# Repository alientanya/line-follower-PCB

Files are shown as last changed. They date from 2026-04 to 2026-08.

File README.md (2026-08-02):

# FLF Bot Modular PCB

A modular PCB platform for Fast Line Follower (FLF) robots, designed to prioritize sensor experimentation and component flexibility.
This board allows multiple sensor array designs to be used interchangeably without redesigning the core electronics.
Instead of committing to a single sensor layout, this PCB supports four distinct sensor array designs, all compatible with the same base system.

---

## Menu

- [Hardware Revisions](#hardware-revisions)
- [Repository Structure](#repository-structure)
- [Core Features](#core-features)  
- [Core Components & Design Choices](#core-components--design-choices)  
- [Sensors](#sensors)  
- [Interchangeable Sensor Arrays](#interchangeable-sensor-arrays)  
- [8+1 Sensor Placement Strategy](#81-sensor-placement-strategy)  
- [Main Control PCB](#main-control-pcb)  
- [MCU Control](#mcu-control)  
- [Detailed Module Documentation](#detailed-module-documentation)
- [Design Considerations](#design-considerations)  
- [License](#license)

---

## Hardware Revisions

- **Lavender 1.0 (Blackpill version)** —   
  Fully designed, fabricated, assembled, and successfully deployed on the physical FLF robot. Uses the STM32F411 Blackpill module.
- **Lavender 2.0 (IC version)** —   
  Work-in-progress experimental design integrating a discrete STM32F411 IC directly onto the PCB.

---

## Repository Structure

```text
├── Lavender 1.0 (Blackpill vers)/    # Hardware-verified revision used on the physical robot
│   ├── line follower simple.kicad_pcb # Main body PCB layout
│   ├── line follower simple.kicad_sch # Main body schematic
│   ├── QRE1113.kicad_sch              # 16-Sensor QRE1113 schematic
│   ├── TCRT_sensors.kicad_sch         # 9-Sensor TCRT5000 schematic
│   ├── customssensor.kicad_sch        # Custom IR LED + PT334 schematic
│   ├── layerconnect.kicad_sch         # Inter-board connector schematic
│   └── FLF_gerbers/                   # Production Gerber output files
├── Lavender 2.0 (IC vers)/           # WIP prototype with discrete STM32 IC
│   ├── STMf411.kicad_sch              # Discrete STM32F411 MCU schematic
│   └── line follower simple.kicad_pcb # 2.0 PCB layout (WIP)
├── PCB customs/                       # 3D STEP models & custom KiCad footprint libraries
├── docs/                              # Detailed hardware documentation guides
│   ├── MODULES.md                     # Circuit modules & subsystem technical reference
│   ├── SENSOR_ARRAYS.md               # Sensor array designs & 8+1 strategy guide
│   └── PINOUTS_AND_REVISIONS.md       # Pin mapping & revision comparison guide
├── images/                            # PCB renders and schematic diagrams
├── LICENSE                            # MIT License
└── README.md                          # Main project README
```

---

## Core Features

* 4 interchangeable sensor array designs
* Modular architecture using headers
* STM32F411 (Blackpill) based control (Lavender 1.0)
* HC-05 Bluetooth connectivity
* Stackable PCB with internal battery space

---

## Core Components & Design Choices

### Microcontroller —  (Blackpill)

* High-speed ADC for sensor reading
* Rich GPIO availability
* Hardware timers for motor PWM
* Plug-in module → easy replacement

---

### Motor Driver — 

* Dual DC motor driver
* Efficient and compact
* Suitable for N20 motors

---

### Voltage Regulation — 

* Buck converter → stable 3.3V
* High efficiency for battery operation
* Adjustable output

---

### Communication — 

* UART-based Bluetooth module
* Used for debugging and tuning
* Supports STATE and EN pins

---

### Analog Multiplexer — 

* 16-channel analog MUX
* Used in high-density sensor configuration
* Reduces MCU pin usage

---

## Sensors

#### 

* Compact reflective IR sensor
* Fast response
* Used in high-density and simple arrays

#### 

* Larger footprint
* More tolerant of alignment and height

#### 

* Discrete design
* Custom Sensors
* Fully tunable sensitivity

---

## Interchangeable Sensor Arrays

All arrays share a common connector interface, making them plug-and-play.

### 1. 16-Sensor Curved Array (QRE1113 + MUX)
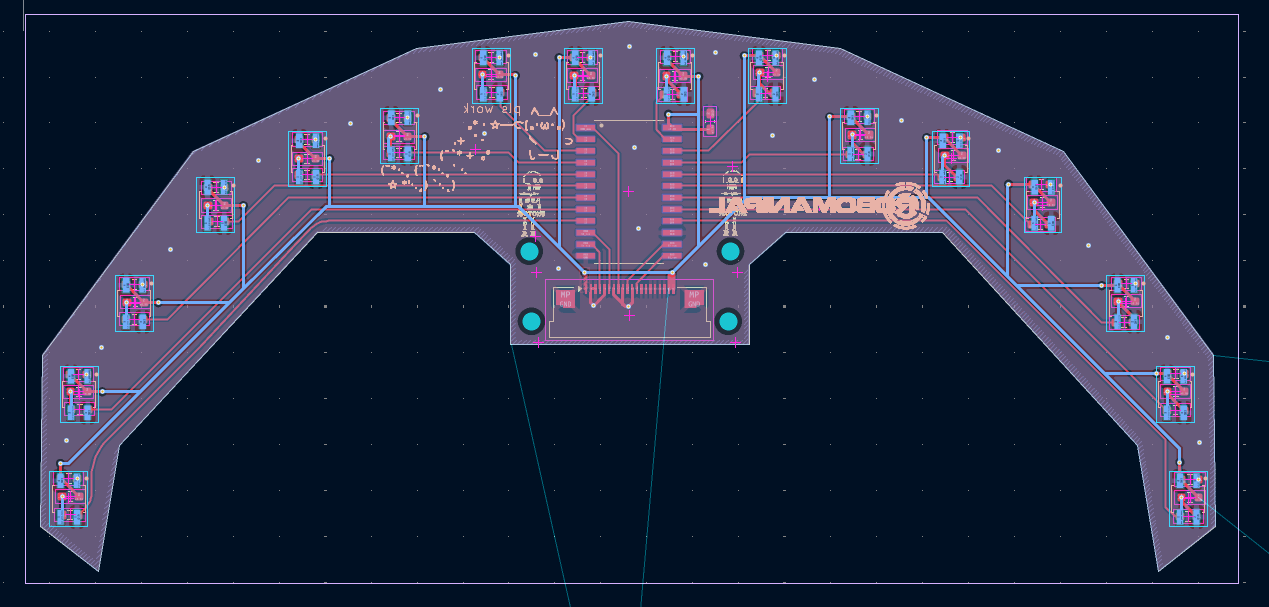
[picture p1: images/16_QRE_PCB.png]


* High resolution                            
* Uses 74HC4067
* Designed for aggressive curves

### 2. 9-Sensor Straight Array (QRE1113)
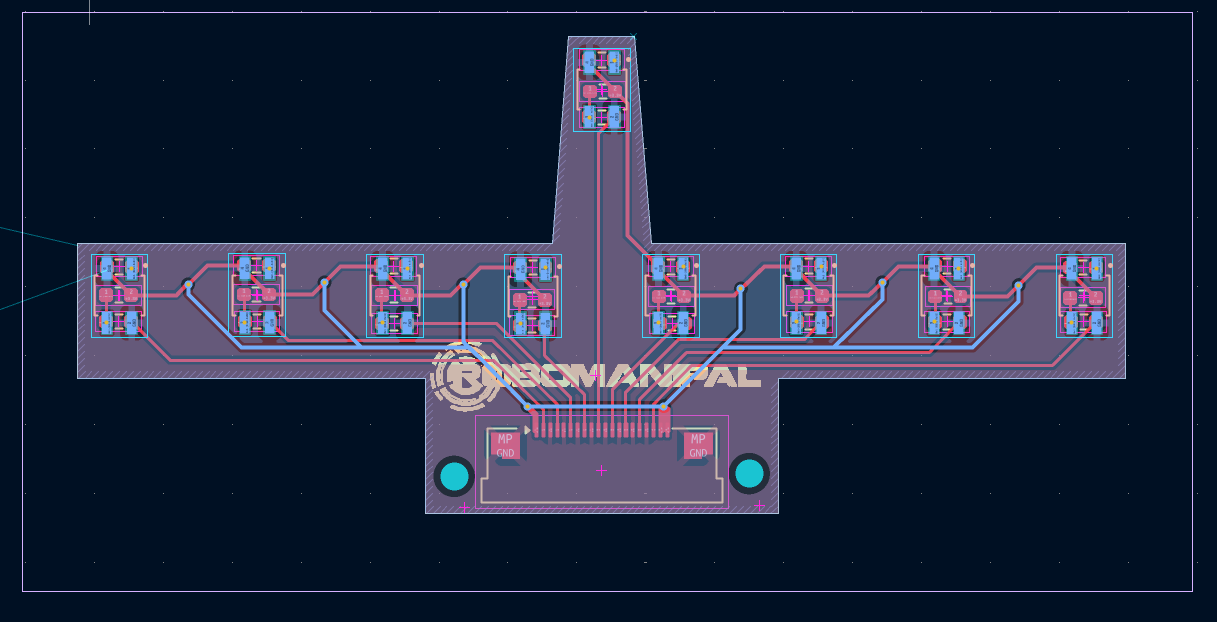
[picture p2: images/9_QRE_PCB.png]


* Direct MCU input
* Low latency
* Simpler processing

### 3. 9-Sensor Curved Array (TCRT5000)
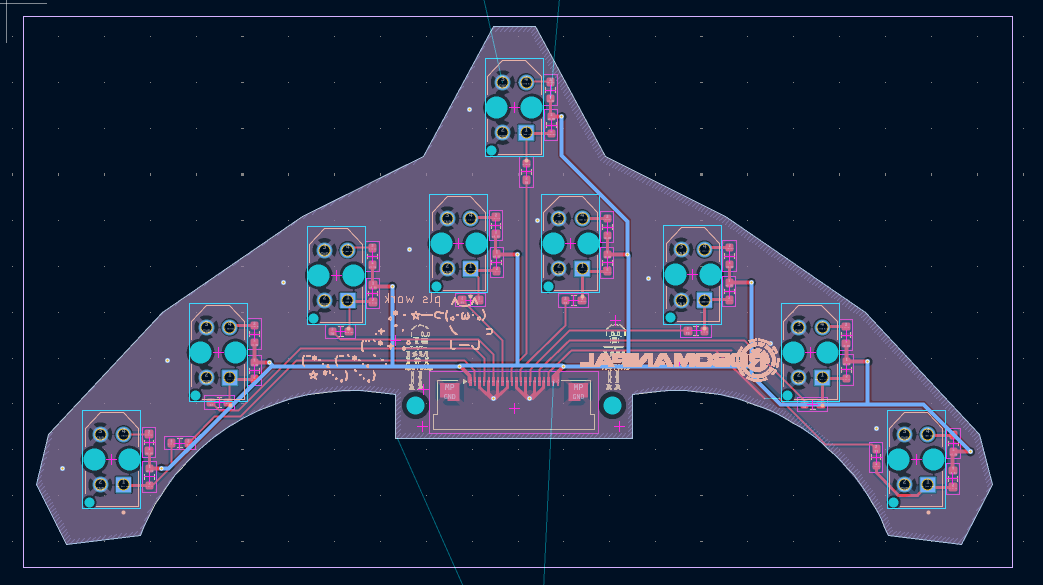
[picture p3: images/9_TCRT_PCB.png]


* Better surface tolerance
* Slight curvature improves tracking

### 4. Custom Sensor Array
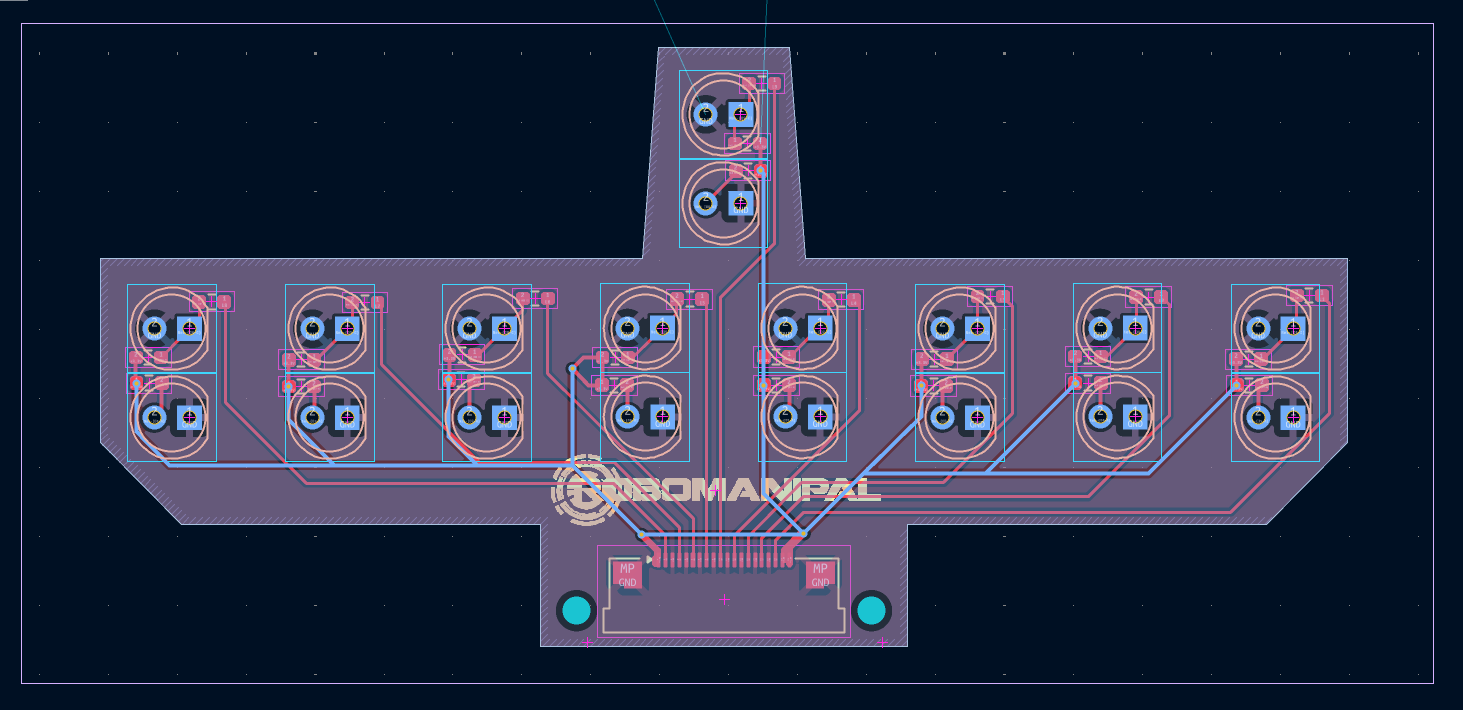
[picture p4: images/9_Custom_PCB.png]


* IR LED + PT334-6C
* Fully customizable behaviour

---

## 8+1 Sensor Placement Strategy

* 8 main sensors → line tracking
* +1 front sensor → overshoot detection

Improves turning accuracy at high speed.

---

## MCU Control

The STM32F411 (Blackpill) acts as the central controller, interfacing with sensors, motor driver, and Bluetooth module.

* Reads sensor data:

  * Direct ADC (for 9-sensor arrays)
  * Via 74HC4067 MUX (for 16-sensor array)
* Processes line position
* Controls motors using PWM + direction pins (TB6612FNG)
* Handles UART communication with HC-05

All sensor arrays use a consistent interface, so firmware changes are minimal when switching configurations.

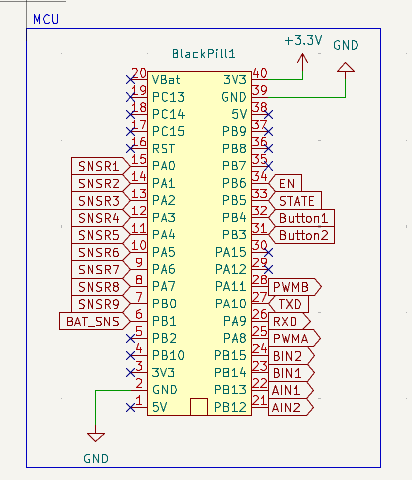
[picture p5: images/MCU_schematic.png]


---

## Main Control PCB

This section describes the core board that handles control, power distribution, and user interaction.

* Hosts the STM32F411 (Blackpill), TB6612FNG motor driver, and HC-05 module
* Separates logic and motor power to reduce noise interference
* Includes dual switches:
  * Motor Kill
  * Battery Kill

* Provides connectors for all interchangeable sensor arrays
* Routes sensor signals (direct or via MUX) to the MCU
* Includes 2 push buttons:
  * Used for control, mode selection, and calibration
  * Hardware debounced (RC)
* Designed as part of a stacked PCB system:
  * Interfaces with the top board via pin headers
  * Creates space between layers for battery placement

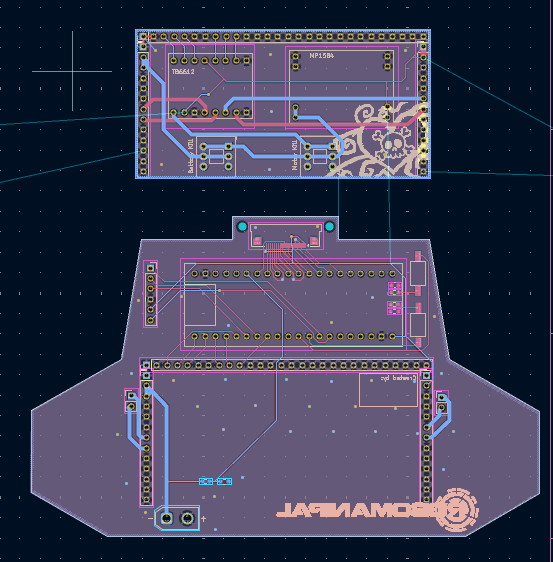
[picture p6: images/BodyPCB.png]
  

---

## Detailed Module Documentation

Explore the dedicated hardware documentation guides for in-depth schematic breakdowns, pinout mappings, and circuit specifications:

- 🔌 **[Circuit Modules & Subsystems Guide](docs/MODULES.md)** — Technical reference for Power Management & Rail Isolation, MCU & SWD Debugging, TB6612FNG Motor Driver, 74HC4067 MUX, Emitter Biasing, RC Hardware Debouncing, and the Inter-Board Header Bus.
- 🎯 **[Interchangeable Sensor Arrays & Placement Strategy](docs/SENSOR_ARRAYS.md)** — Comprehensive breakdown of the 4 sensor array variants (16-QRE MUX, 9-QRE, 9-TCRT, Custom Discrete) and the 8+1 apex placement geometry.
- 📌 **[Pin Mapping & Hardware Revisions Guide](docs/PINOUTS_AND_REVISIONS.md)** — Hardware peripheral pin assignments (PWM, ADC, MUX select, UART), SWD interface, and comparison between Lavender 1.0 (Field-Tested) and Lavender 2.0 (WIP).

---

## Design Considerations

- Tradeoff between sensor resolution and sampling speed (MUX vs direct ADC)
- Separation of motor and logic power to reduce noise
- Modular sensor interface to allow rapid hardware iteration
- Use of off-the-shelf modules (MCU, driver, regulator) for reliability and easy replacement
- Support for multiple sensor geometries to evaluate performance under different track conditions

---

## Summary

Instead of locking the design into a single sensor configuration, this PCB is built as a flexible platform that encourages rapid experimentation and iteration. Supporting multiple interchangeable sensor arrays, it allows direct comparison between different sensing approaches, geometries, and component choices under the same hardware conditions. This makes it easier to fine-tune performance, optimise control algorithms, and adapt the system for different track types. Ultimately, the goal of this design is not just to work, but to provide a reliable foundation for continuously improving and pushing the limits of FLF performance.

---

## License

This project is licensed under the MIT License — see the [LICENSE](LICENSE) file for details.

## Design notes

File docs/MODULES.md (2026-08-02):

# Hardware Module Documentation

This document provides a detailed breakdown of the functional modules, power circuits, controller revisions, and interchangeable sensor arrays used in the **FLF Bot Modular PCB** platform.

---

## 1. Hardware Revisions

| Revision | Architecture | Status | Notes |
| :--- | :--- | :--- | :--- |
| **Lavender 1.0** | STM32F411 Blackpill Breakout | **Ready & Field-Tested** | Printed, assembled, and successfully deployed on the physical FLF competition robot. |
| **Lavender 2.0** | Discrete STM32F411 IC Onboard | **Work in Progress (WIP)** | Experimental revision integrating discrete MCU IC directly onto the main PCB. Not yet fabricated. |

---

## 2. Power Management Module

The power distribution system is designed to isolate sensitive digital controller logic from high-current motor inductive noise.

- **Primary Voltage Regulator**: MP1584 Step-Down (Buck) DC-DC Converter.
  - **Input Voltage**: 2S / 3S LiPo battery (7.4V – 11.1V nominal).
  - **Output Voltage**: Clean 3.3V rail powering the STM32 MCU, 74HC4067 MUX, sensors, and HC-05 module.
  - **Efficiency**: High efficiency reduces heat generation during long runs.
- **Power Rail & Ground Isolation**: Logic supply (3.3V) and motor supply (VCC/VM) run on isolated power traces with dedicated bulk decoupling capacitors (electrolytic + ceramic) across motor supply lines to absorb inductive back-EMF spikes.
- **Dual Safety Kill Switches**:
  - **Battery Kill Switch**: Completely isolates the LiPo battery from the entire board.
  - **Motor Kill Switch**: Cuts power exclusively to the TB6612FNG motor driver `VM` rail while keeping MCU logic and Bluetooth active for telemetry and calibration.

---

## 3. Microcontroller Module & Debug Interface

### Lavender 1.0 (Blackpill Breakout) — *Field Tested*
- **MCU Core**: STM32F411CEU6 (ARM Cortex-M4 @ 100MHz, 512KB Flash, 128KB SRAM).
- **Form Factor**: Plug-in daughterboard headers.
- **Advantages**:
  - Modular replacement in case of overvoltage or pin damage during field testing.
  - Integrated USB-C port for rapid DFU/ST-Link flashing.
  - Onboard 25MHz HSE crystal and 32.768kHz LSE crystal.

### Lavender 2.0 (Discrete IC) — *Work In Progress*
- **MCU Core**: Surface-mount STM32F411 IC directly soldered to the main PCB (`STMf411.kicad_sch`).
- **Features**: Dedicated SWD (Serial Wire Debug) header, external HSE crystal circuit, decoupling capacitor network, and boot mode configuration resistors.

### SWD Debug & Programming Header
- Breakout header (`SWDIO`, `SWCLK`, `GND`, `3.3V`) providing direct in-circuit programming and live step-debugging via ST-Link V2/V3 hardware debuggers.

---

## 4. Motor Driver Module

- **IC**: Toshiba TB6612FNG Dual H-Bridge Driver.
- **Application**: Controls two micro N20 DC gearmotors (Left Motor & Right Motor).
- **Interfaces**:
  - **PWM Pins (PWMA, PWMB)**: Connected to STM32 hardware timer outputs for precise motor speed control.
  - **Direction Pins (AIN1/2, BIN1/2)**: GPIO lines controlling forward, reverse, and braking modes.
  - **Standby (STBY)**: Tied to MCU GPIO for emergency driver shutdown.
- **Protection**: Onboard decoupling capacitors to absorb voltage spikes and back-EMF generated by the motors.

---

## 5. Analog Signal Multiplexing

- **IC**: Texas Instruments 74HC4067 (16-Channel Analog Multiplexer / Demultiplexer).
- **Role**: Expands the MCU's analog sensing capability for high-density sensor arrays without consuming 16 separate ADC pins.
- **Control Interface**:
  - **Select Lines (S0, S1, S2, S3)**: 4 digital outputs from the STM32 select one of the 16 channels.
  - **Enable Line (EN)**: Active-low enable pin connected to ground/MCU GPIO.
  - **Signal Line (SIG)**: Common multiplexed analog output fed directly into an STM32 ADC channel.

---

## 6. Interchangeable Sensor Array Modules

All sensor arrays connect to the main body PCB via a standardized header interface (`layerconnect.kicad_sch`).

### 1. 16-Sensor Curved Array (QRE1113 + 74HC4067 MUX)
- **Sensor IC**: 16x QRE1113 miniature reflective IR phototransistors.
- **Topology**: Curved geometry following line entry angles.
- **Routing**: Routed through 74HC4067 MUX → single MCU ADC channel.
- **Best Use Case**: High-resolution line tracking for sharp turns and complex curves.

### 2. 9-Sensor Straight Array (QRE1113)
- **Sensor IC**: 9x QRE1113 optical sensors.
- **Topology**: Straight linear arrangement.
- **Routing**: Direct pin mapping to 9 dedicated STM32 ADC channels.
- **Best Use Case**: Minimum latency sampling and fast straight-line acceleration.

### 3. 9-Sensor Curved Array (TCRT5000)
- **Sensor IC**: 9x TCRT5000 reflective optical sensors.
- **Topology**: Slightly curved front layout.
- **Characteristics**: Wider sensing distance tolerance, ideal for non-uniform track surfaces.

### 4. Custom Discrete Sensor Array
- **Components**: Discrete IR Emitters (LEDs) + PT334-6C Phototransistors.
- **Features**: Individual bias resistors and tuning load resistor networks for custom sensitivity calibration.

---

## 7. Emitter Biasing & Phototransistor Load Networks

- **IR Emitter Current Limiting**: Series resistor arrays calculated to supply optimal forward current to IR LEDs without exceeding power limits or overheating.
- **Phototransistor Load Resistors**: Precision pull-down load resistors converting phototransistor collector current into sharp, low-noise analog voltage levels for MCU ADC sampling.

---

## 8. 8+1 Sensor Placement Strategy

- **8 Main Sensors**: Form the primary array positioned along the front arc for continuous PID line-position estimation.
- **+1 Overshoot Sensor**: Placed further ahead at the front apex. Detects upcoming turn entries, sharp 90° corners, or line loss early, triggering pre-programmed braking or turn-entry algorithms before the main array loses tracking.

---

## 9. Wireless Telemetry, Debounced UI & Diagnostics

- **Bluetooth Module (HC-05)**:
  - Connected to STM32 USART port.
  - Used for real-time PID tuning, live sensor data streaming, and telemetry logging without tethering a cable.
  - Includes `STATE` and `EN` line breakouts for connection state monitoring.
- **Hardware-Debounced Tactile Switches**:
  - 2 user-configurable push buttons.
  - Dedicated **RC Low-Pass Filter Networks** (resistor + capacitor pairs) connected across button contacts to hardware-bounce-filter mechanical contacts before signals reach STM32 GPIO pins.
  - Used for sensor calibration, mode selection, or launching runs.
- **Visual Status LEDs**: Onboard diagnostic LEDs providing instant visual indication for 3.3V power availability and system execution states.

---

## 10. Inter-Board Header Bus & Mechanical Stacking

- **Layer Connection Header (`layerconnect.kicad_sch`)**: Multi-pin connector array bridging power (3.3V, GND), 16 analog MUX signals, and direct sensor lines between the main control PCB and sensor plates.
- **3D Stacked Frame Construction**: Standoff mounting holes (`H1`-`H12`) lock the main PCB and top plate into a rigid chassis, leaving a central cavity designed specifically to fit 2S/3S LiPo batteries while maintaining a low center of gravity.

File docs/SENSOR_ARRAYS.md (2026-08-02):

# Interchangeable Sensor Arrays & Placement Strategy

The **FLF Bot Modular PCB** platform features a standardized, interchangeable sensor array interface. By using common inter-board header pinouts (`layerconnect.kicad_sch`), the robot can switch between different optical sensing technologies and array geometries without modifying the main control board or MCU wiring.

---

## 1. Sensor Array Variants

### Array 1: 16-Sensor Curved Array (QRE1113 + 74HC4067 MUX)
- **Primary Component**: 16x Fairchild/ON Semi QRE1113 miniature reflective phototransistors.
- **Multiplexing**: 74HC4067 16-channel analog MUX converts 16 analog signals down to 1 multiplexed output line (`SIG`).
- **Geometry**: Parabolic curved arc.
- **Key Advantage**: Maximum spatial resolution across aggressive curves and acute turns.
- **Sampling Scheme**: Sequential channel switching via digital control lines `S0`, `S1`, `S2`, `S3`.

---

### Array 2: 9-Sensor Straight Array (QRE1113)
- **Primary Component**: 9x QRE1113 reflective IR sensors.
- **Multiplexing**: Direct ADC sampling (no MUX latency).
- **Geometry**: Straight linear row.
- **Key Advantage**: Zero multiplexing delay and ultra-fast sampling throughput. Ideal for high-speed straight-line acceleration.

---

### Array 3: 9-Sensor Curved Array (TCRT5000)
- **Primary Component**: 9x Vishay TCRT5000 reflective optical sensors.
- **Multiplexing**: Direct ADC sampling.
- **Geometry**: Slightly curved arc.
- **Key Advantage**: Larger optical footprint with higher height tolerance ($0.2\text{mm} - 15\text{mm}$). Ideal for irregular or textured track surfaces.

---

### Array 4: Custom Discrete Sensor Array (IR LED + PT334-6C)
- **Primary Component**: High-output 940nm IR Emitters + PT334-6C Phototransistors.
- **Features**: Individual current-limiting resistors and tunable load resistor networks.
- **Key Advantage**: Complete manual control over optical wavelength, emitter power, and sensor sensitivity.

---

## 2. The 8+1 Sensor Placement Strategy

```text
               [ Front Overshoot Sensor (+1) ]
                            │
               ┌────────────┴────────────┐
               │    Front Apex Detection │
               └─────────────────────────┘
                            ▲
                            │ (Braking & Turn Entry Trigger)
                            │
   [S1]  [S2]  [S3]  [S4]       [S5]  [S6]  [S7]  [S8]
    └─────────────────┬───────────────────┘
               8 Main Tracking Arc
            (Continuous PID Line Position)
```

### Functional Breakdown
1. **8 Main Line Tracking Sensors**:
   - Form an arc positioned at the optimal turning pivot distance.
   - Outputs are processed through a weighted average formula to calculate continuous line error ($e(t)$) for PID motor control:
     $$\text{Position} = \frac{\sum_{i=1}^{8} w_i \cdot S_i}{\sum_{i=1}^{8} S_i}$$
2. **+1 Front Overshoot Sensor**:
   - Positioned further ahead at the front apex.
   - Detects upcoming 90° corners, T-junctions, cross-tracks, or sudden line loss before the main array reaches the turn.
   - Triggers pre-programmed corner-entry deceleration or aggressive yaw rotation algorithms.

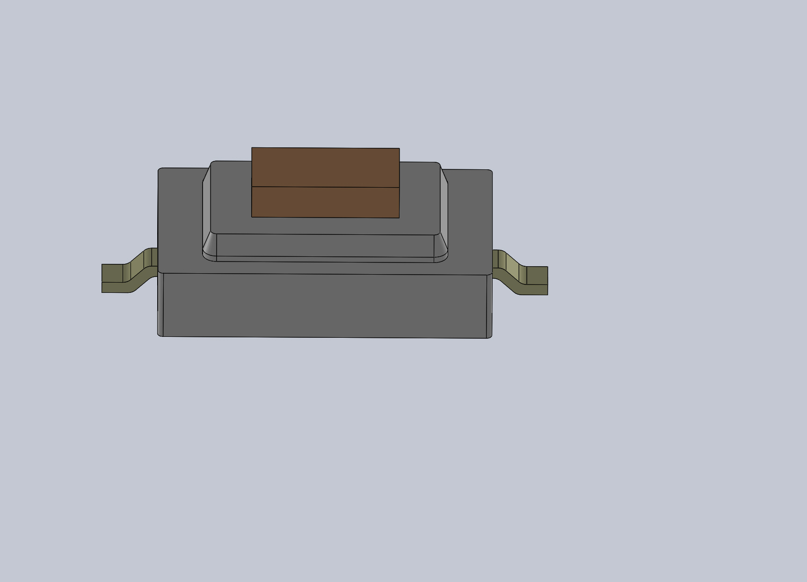
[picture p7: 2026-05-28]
PCB customs/g73-6x3-5-mm-smd-button-1.snapshot.1/G73 button.JPG

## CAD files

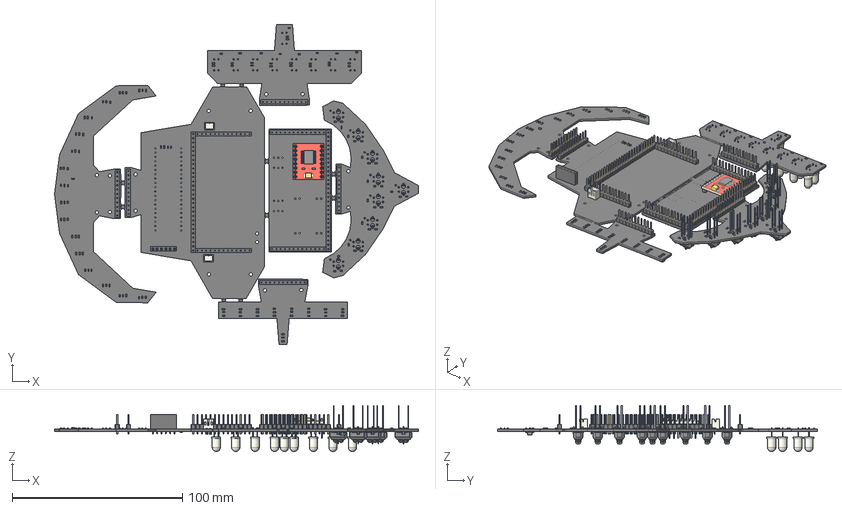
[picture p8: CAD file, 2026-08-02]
Lavender 1.0 (Blackpill vers)/.step
214.0 x 187.9 x 27.1 mm
R_0603_1608Metric x 133
C_0603_1608Metric x 3
PinHeader_1x11_P2.54mm_Vertical x 5
TB6612FNG_Lower Pins
PinHeader_1x13_P2.54mm_Vertical x 4
PinSocket_1x06_P2.54mm_Vertical
PinHeader_1x28_P2.54mm_Vertical x 2
JST_PH_B2B-PH-K_1x02_P2.00mm_Vertical x 2
TCRT5000L x 9
LED_D5.0mm_Clear x 18
Fuse_0805_2012Metric
QRE1113GR--3DModel-STEP-418109
line follower simple_PCB

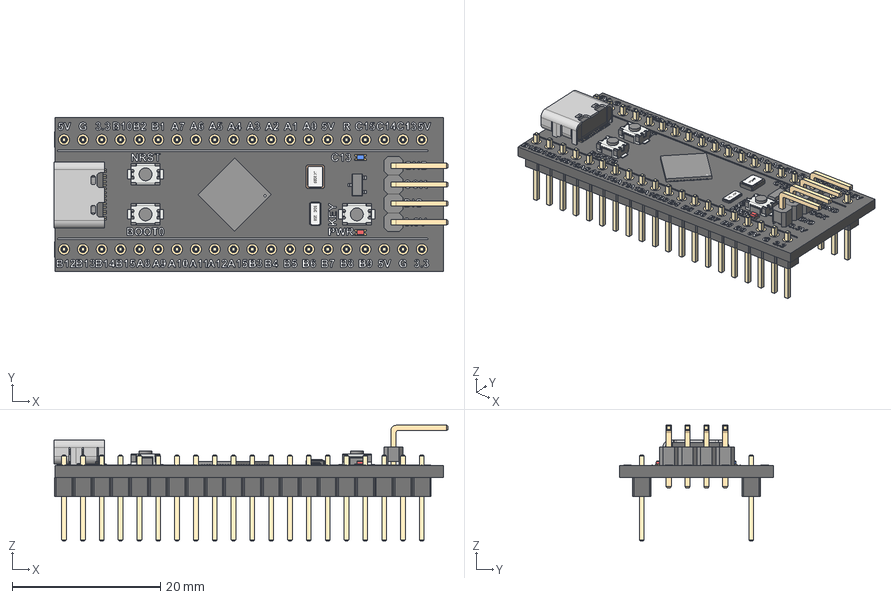
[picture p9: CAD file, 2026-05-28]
PCB customs/blackpill_f4x1-1.snapshot.1/minif4_stm32f401_stm32f411_board.step
53.1 x 20.8 x 15.6 mm
USB_Type_C_12pin
UFQFPN48
Pushbutton3x4x2 x 3
SOT-23
Crystal_3225_(Resonator)
Crystal_Siward_SX3215_(Resonator)
PLS-10 x 4
PLS-4R gold

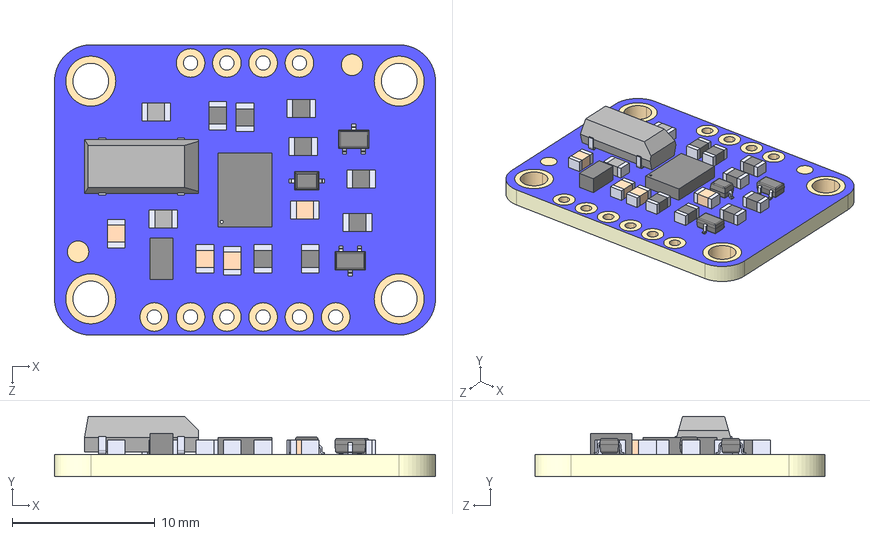
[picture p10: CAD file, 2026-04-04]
PCB customs/BNO055 module/2472.step
26.7 x 4.23 x 20.3 mm
BNO055_BNO055
BSS138_BSS138 x 2
1N4148_1N4148
32.768kHz_32.768kHz

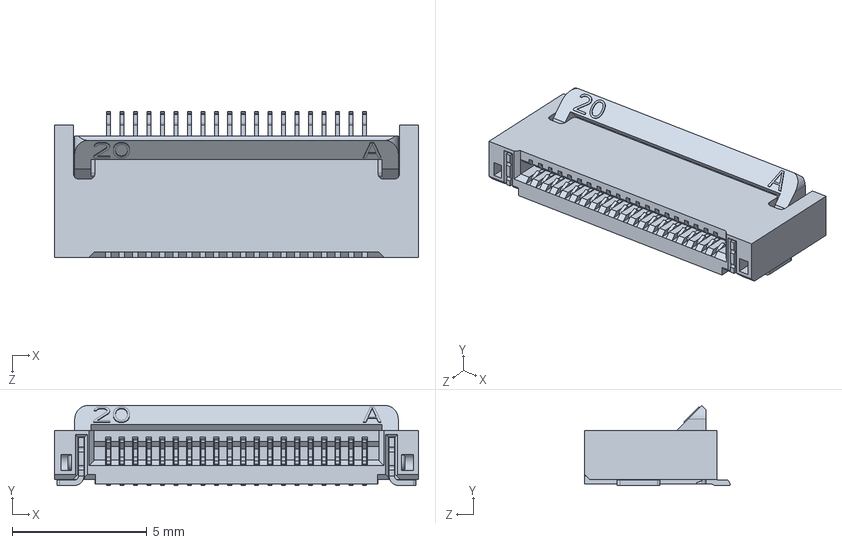
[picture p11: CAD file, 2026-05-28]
PCB customs/FPC-05FB-20PH20.SLDPRT
13.5 x 2.97 x 5.40 mm

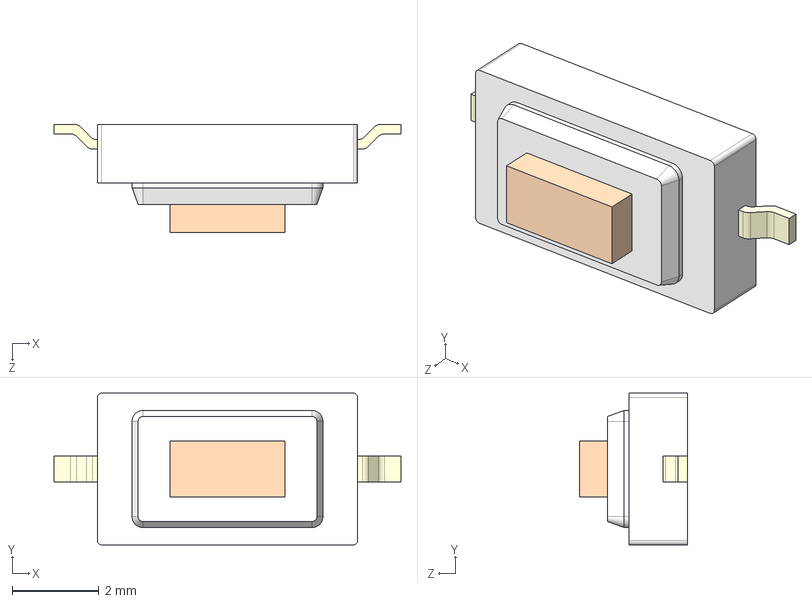
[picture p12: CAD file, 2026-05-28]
PCB customs/g73-6x3-5-mm-smd-button-1.snapshot.1/G73 button.STEP
8.00 x 3.50 x 2.50 mm

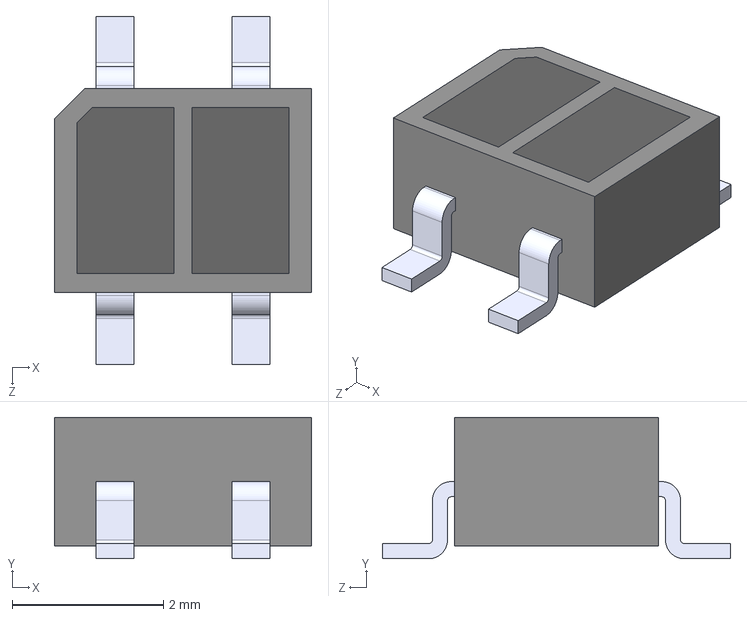
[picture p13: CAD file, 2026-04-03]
PCB customs/QRE1113GR/QRE1113GR.step
3.40 x 1.87 x 4.60 mm

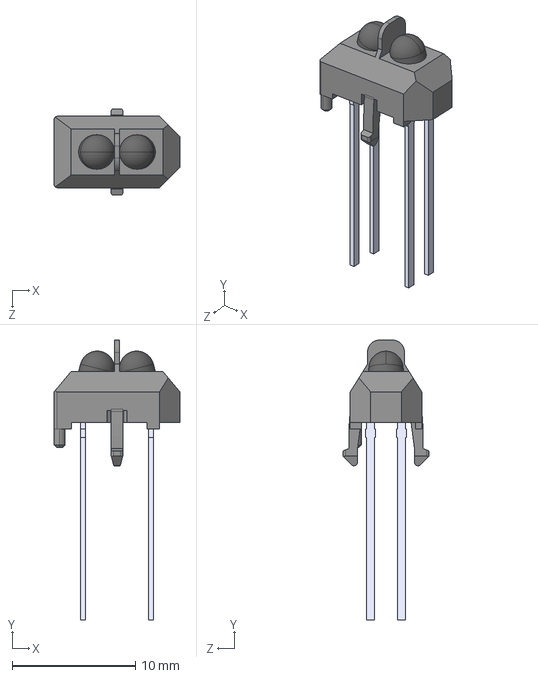
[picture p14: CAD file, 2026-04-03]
PCB customs/TCRT5000L/TCRT5000L.step
10.2 x 22.7 x 7.00 mm

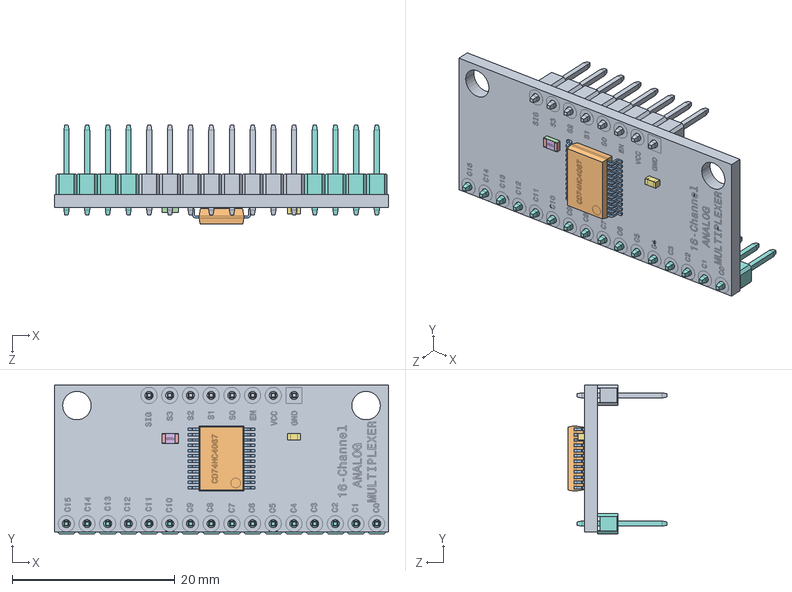
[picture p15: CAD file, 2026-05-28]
PCB customs/Assem4.STEP
41.0 x 18.2 x 12.1 mm
PCB MUX 16 CANALI_Varsay考an
CD74HC4067_23_Varsay考an
CD74HC4067_18_Varsay考an
CD74HC4067_16_Varsay考an
CD74HC4067_8_Varsay考an
CD74HC4067_5_Varsay考an
CD74HC4067_10_Varsay考an
CD74HC4067_9_Varsay考an
CD74HC4067_7_Varsay考an
CD74HC4067_6_Varsay考an
CD74HC4067_14_Varsay考an
CD74HC4067_2_Varsay考an
CD74HC4067_21_Varsay考an
CD74HC4067_24_Varsay考an
CD74HC4067_1_Varsay考an
CD74HC4067_15_Varsay考an
CD74HC4067_12_Varsay考an
CD74HC4067_3_Varsay考an
CD74HC4067_19_Varsay考an
CD74HC4067_13_Varsay考an
CD74HC4067_4_Varsay考an
CD74HC4067_Varsay考an
CD74HC4067_22_Varsay考an
CD74HC4067_17_Varsay考an
CD74HC4067_11_Varsay考an
CD74HC4067_20_Varsay考an
SMD RESISTOR 0805_Varsay考an
SMD RESISTOR 0805_1_Varsay考an
SMD RESISTOR 0805_2_Varsay考an
SMD RESISTOR 0805_3_Varsay考an
SMD CAPACITOR 0603_Varsay考an
16_Varsay考an
8_Varsay考an

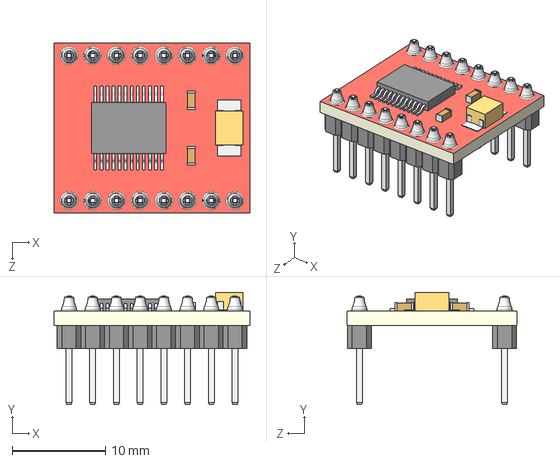
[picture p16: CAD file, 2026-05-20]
PCB customs/TB6612FNG_Lower Pins.STEP
21.0 x 12.1 x 18.2 mm

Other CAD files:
PCB customs/g73-6x3-5-mm-smd-button-1.snapshot.1/G73 button.SLDPRT

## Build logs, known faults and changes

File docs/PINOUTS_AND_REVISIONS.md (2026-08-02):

# Pin Mapping & Hardware Revisions Guide

This document details the STM32F411 microcontroller pin allocation, hardware peripheral assignments (PWM, ADC, UART, GPIO), and comparison between hardware revisions.

---

## 1. Hardware Revisions Comparison

| Specification | Lavender 1.0 (Blackpill) | Lavender 2.0 (IC Version) |
| :--- | :--- | :--- |
| **Status** | **Field-Tested & Operational** | **Work In Progress (WIP)** |
| **Microcontroller Form** | Plug-in Blackpill Breakout | Onboard Discrete STM32F411 IC |
| **USB Interface** | Onboard Blackpill USB-C Port | External SWD / USB breakout |
| **Crystal Oscillator** | 25MHz HSE on daughterboard | Onboard 25MHz Crystal + Load Caps |
| **Repairability** | Modular daughterboard swap | Component-level rework |
| **Physical Deployment** | Deployed on competition FLF robot | Unfabricated prototype |

---

## 2. STM32F411 Microcontroller Pin Allocation

### Motor Driver (TB6612FNG) Mapping
- **Motor Left PWM (`PWMA`)**: Hardware Timer Output (e.g. `TIM2_CH1` / `PA0`)
- **Motor Right PWM (`PWMB`)**: Hardware Timer Output (e.g. `TIM2_CH2` / `PA1`)
- **Motor Left Direction (`AIN1`, `AIN2`)**: Digital Output GPIOs
- **Motor Right Direction (`BIN1`, `BIN2`)**: Digital Output GPIOs
- **Motor Driver Standby (`STBY`)**: Active-high GPIO Enable

---

### Analog Multiplexer (74HC4067) Mapping
- **Channel Select `S0`**: Digital Output GPIO
- **Channel Select `S1`**: Digital Output GPIO
- **Channel Select `S2`**: Digital Output GPIO
- **Channel Select `S3`**: Digital Output GPIO
- **Multiplexer Enable (`EN`)**: Active-low GND / GPIO
- **Multiplexer Signal (`SIG`)**: STM32 ADC Channel (`ADC1_IN0` / `PA0` or designated ADC pin)

---

### Telemetry & Debug Interface
- **HC-05 Bluetooth TX / RX**: USART1 / USART2 (`TX` / `RX` pins)
- **SWD Debugging**: `SWDIO` (PA13), `SWCLK` (PA14)
- **User Buttons (RC Debounced)**: GPIO Inputs with internal pull-up / pull-down configuration

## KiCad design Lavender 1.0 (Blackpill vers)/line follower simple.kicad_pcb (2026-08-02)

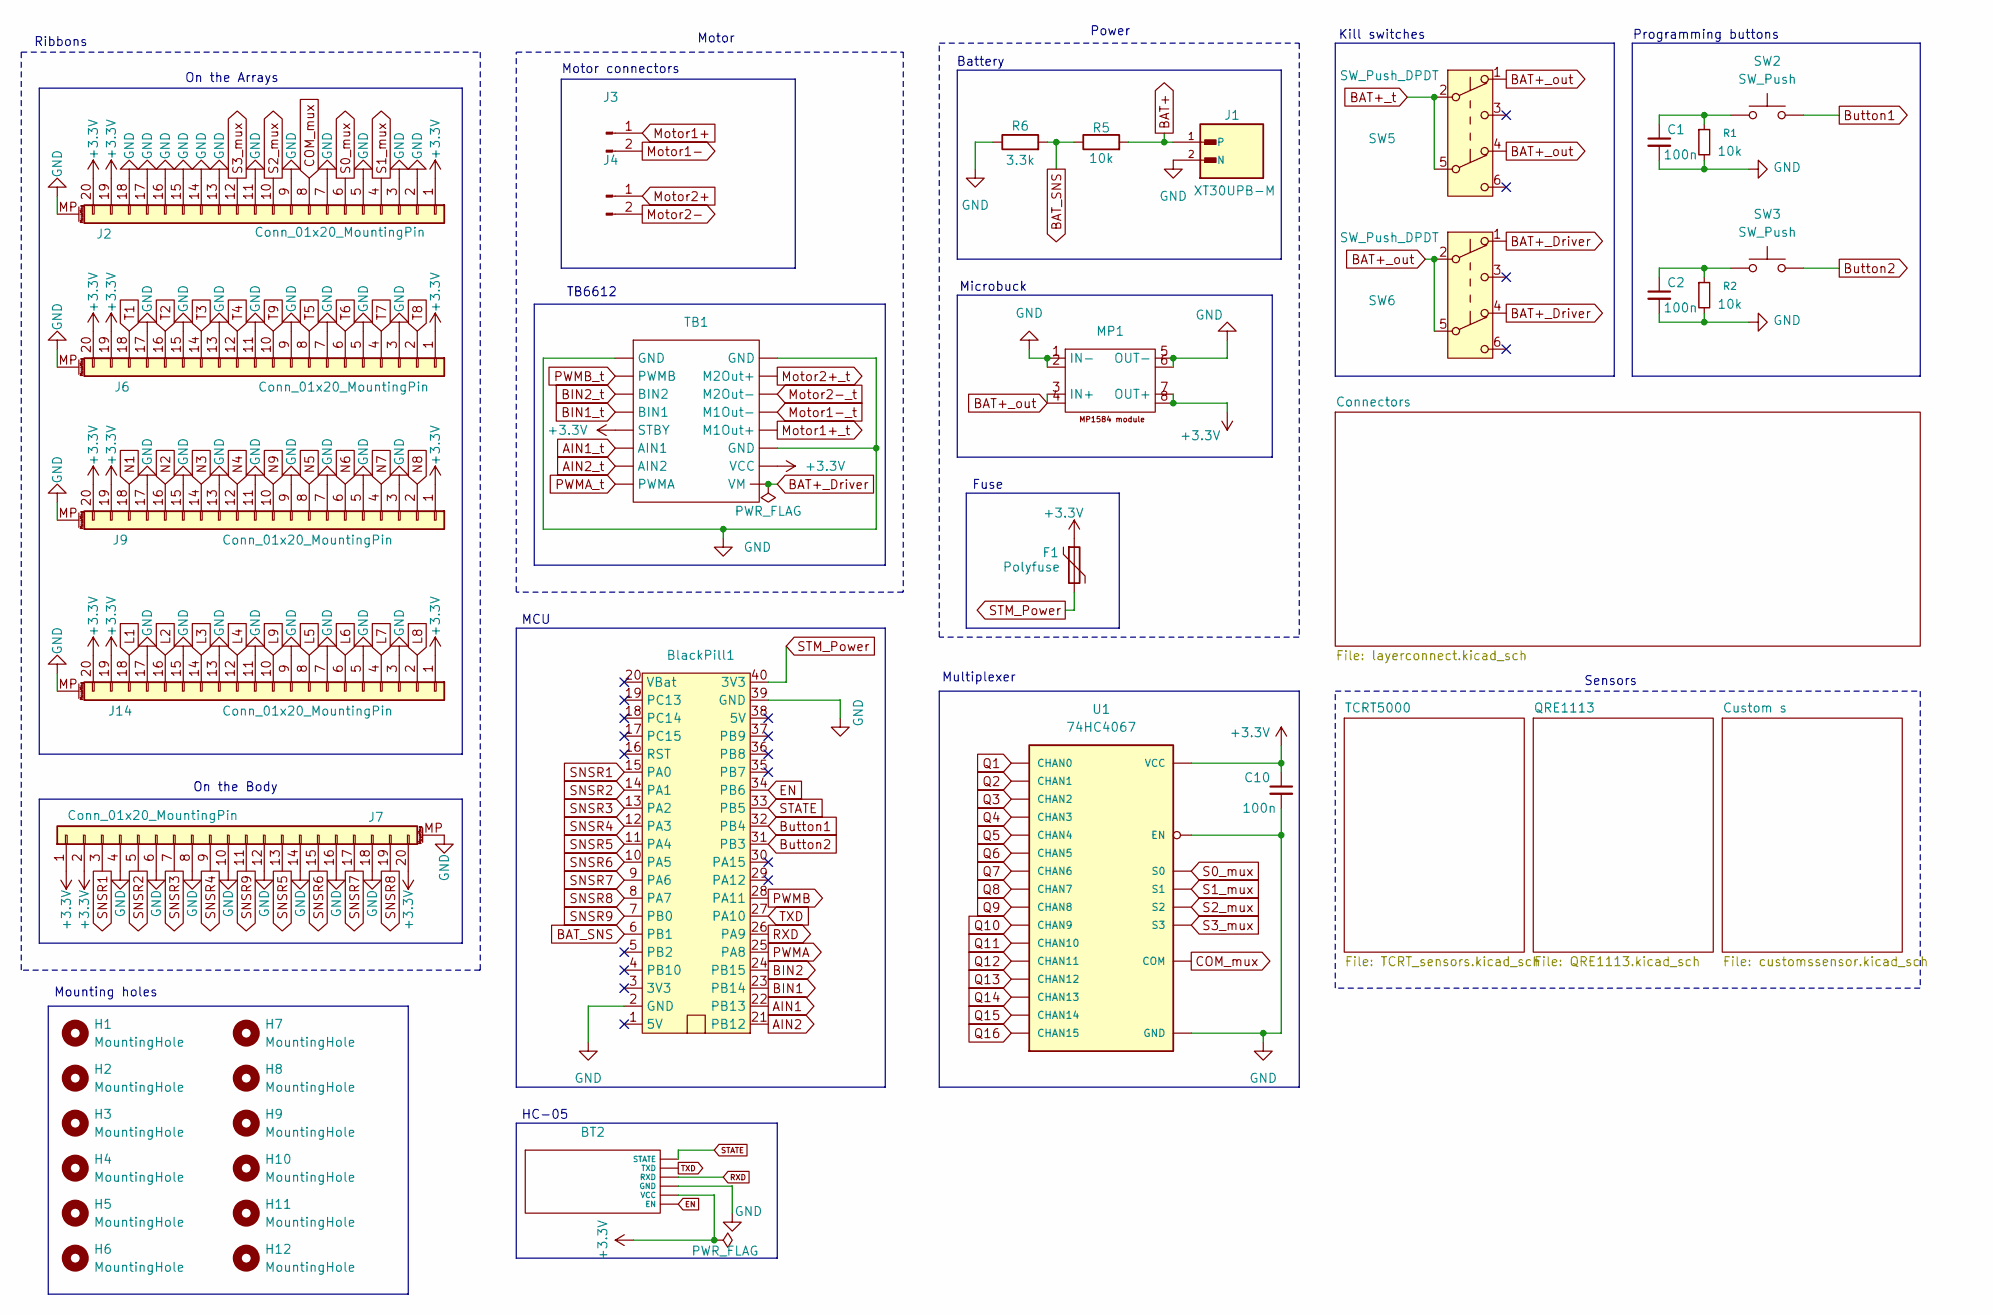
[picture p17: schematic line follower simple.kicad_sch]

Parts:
BT2: PinSocket_1x06_P2.54mm_Vertical
BlackPill1: STM32F411_BP; blackpill_fp
C1, C2, C10: 100n; C_0603_1608Metric_Pad1.08x0.95mm_HandSolder
F1: Polyfuse; Fuse_0805_2012Metric_Pad1.15x1.40mm_HandSolder
H1, H2, H3, H4, H5, H6, H7, H8, H9, H10, H11, H12: MountingHole; 2mm hole
J1: XT30UPB-M; AMASS_XT30UPB-M_1x02_P5.0mm_Vertical
J2, J6, J7, J9, J14: Conn_01x20_MountingPin; Amphenol_F32Q-1A7x1-11020_1x20-1MP_P0.5mm_Horizontal
J3, J4: Conn_01x02_Pin; JST_PH_B2B-PH-K_1x02_P2.00mm_Vertical
MP1: MP1584_fp
R1, R2, R5: 10k; R_0603_1608Metric_Pad0.98x0.95mm_HandSolder
R6: 3.3k; R_0603_1608Metric_Pad0.98x0.95mm_HandSolder
SW2, SW3: SW_Push; Push button-fp
SW5, SW6: SW_Push_DPDT; SW_Push_2P2T_Toggle_CK_PVA2xxH3xxxxxxV2
TB1: TB6612 module
U1: 74HC4067; 74HC4067-Mux

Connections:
+3.3V: BT2.5 (VCC), C10.1, F1.1, J2.1, J2.19, J2.20, J6.1, J6.19, J6.20, J7.1, J7.2, J7.20, J9.1, J9.19, J9.20, J14.1, J14.19, J14.20, MP1.7 (OUT+), MP1.8, TB1.5 (STBY), TB1.15 (VCC), U1.P24 (VCC); also elsewhere on the board
AIN1: BlackPill1.22 (PB13); also elsewhere on the board
AIN1_t: TB1.6 (AIN1); also elsewhere on the board
AIN2: BlackPill1.21 (PB12); also elsewhere on the board
AIN2_t: TB1.7 (AIN2); also elsewhere on the board
BAT+: J1.1, R5.2; also elsewhere on the board
BAT+_Driver: SW6.1 (A), SW6.4 (A), TB1.16 (VM)
BAT+_out: MP1.3 (IN+), MP1.4, SW5.1 (A), SW5.4 (A), SW6.2 (B), SW6.5 (B)
BAT+_t: SW5.2 (B), SW5.5 (B); also elsewhere on the board
BAT_SNS: BlackPill1.6 (PB1), R5.1, R6.2
BIN1: BlackPill1.23 (PB14); also elsewhere on the board
BIN1_t: TB1.4 (BIN1); also elsewhere on the board
BIN2: BlackPill1.24 (PB15); also elsewhere on the board
BIN2_t: TB1.3 (BIN2); also elsewhere on the board
Button1: BlackPill1.32 (PB4), SW2.2
Button2: BlackPill1.31 (PB3), SW3.2
COM_mux: J2.8, U1.P1 (COM); also elsewhere on the board
EN: BT2.6 (EN), BlackPill1.34 (PB6)
GND: BT2.4 (GND), BlackPill1.2 (GND), BlackPill1.39 (GND), C1.2, C2.2, C10.2, J1.2 (N), J2.2, J2.3, J2.5, J2.7, J2.9, J2.11, J2.13, J2.14, J2.15, J2.16, J2.17, J2.18, J2.MP (MountPin), J6.3, J6.5, J6.7, J6.9, J6.11, J6.13, J6.15, J6.17, J6.MP (MountPin), J7.4, J7.6, J7.8, J7.10, J7.12, J7.14, J7.16, J7.18, J7.MP (MountPin), J9.3, J9.5, J9.7, J9.9, J9.11, J9.13, J9.15, J9.17, J9.MP (MountPin), J14.3, J14.5, J14.7, J14.9, J14.11, J14.13, J14.15, J14.17, J14.MP (MountPin), MP1.1 (IN-), MP1.2, MP1.5 (OUT-), MP1.6, R1.2, R2.2, R6.1, TB1.1 (GND), TB1.9 (GND), TB1.14 (GND), U1.P12 (GND), U1.P15 (EN); also elsewhere on the board
L1: J14.18; also elsewhere on the board
L2: J14.16; also elsewhere on the board
L3: J14.14; also elsewhere on the board
L4: J14.12; also elsewhere on the board
L5: J14.8; also elsewhere on the board
L6: J14.6; also elsewhere on the board
L7: J14.4; also elsewhere on the board
L8: J14.2; also elsewhere on the board
L9: J14.10; also elsewhere on the board
Motor1+: J3.1; also elsewhere on the board
Motor1+_t: TB1.13 (M1Out+); also elsewhere on the board
Motor1-: J3.2; also elsewhere on the board
Motor1-_t: TB1.12 (M1Out-); also elsewhere on the board
Motor2+: J4.1; also elsewhere on the board
Motor2+_t: TB1.10 (M2Out+); also elsewhere on the board
Motor2-: J4.2; also elsewhere on the board
Motor2-_t: TB1.11 (M2Out-); also elsewhere on the board
N1: J9.18; also elsewhere on the board
N2: J9.16; also elsewhere on the board
N3: J9.14; also elsewhere on the board
N4: J9.12; also elsewhere on the board
N5: J9.8; also elsewhere on the board
N6: J9.6; also elsewhere on the board
N7: J9.4; also elsewhere on the board
N8: J9.2; also elsewhere on the board
N9: J9.10; also elsewhere on the board
unnamed: C1.1, R1.1, SW2.1
unnamed: C2.1, R2.1, SW3.1
PWMA: BlackPill1.25 (PA8); also elsewhere on the board
PWMA_t: TB1.8 (PWMA); also elsewhere on the board
PWMB: BlackPill1.28 (PA11); also elsewhere on the board
PWMB_t: TB1.2 (PWMB); also elsewhere on the board
Q1: U1.P9 (CHAN0); also elsewhere on the board
Q2: U1.P8 (CHAN1); also elsewhere on the board
Q3: U1.P7 (CHAN2); also elsewhere on the board
Q4: U1.P6 (CHAN3); also elsewhere on the board
Q5: U1.P5 (CHAN4); also elsewhere on the board
Q6: U1.P4 (CHAN5); also elsewhere on the board
Q7: U1.P3 (CHAN6); also elsewhere on the board
Q8: U1.P2 (CHAN7); also elsewhere on the board
Q9: U1.P23 (CHAN8); also elsewhere on the board
Q10: U1.P22 (CHAN9); also elsewhere on the board
Q11: U1.P21 (CHAN10); also elsewhere on the board
Q12: U1.P20 (CHAN11); also elsewhere on the board
Q13: U1.P19 (CHAN12); also elsewhere on the board
Q14: U1.P18 (CHAN13); also elsewhere on the board
Q15: U1.P17 (CHAN14); also elsewhere on the board
Q16: U1.P16 (CHAN15); also elsewhere on the board
RXD: BT2.3 (RXD), BlackPill1.26 (PA9)
S0_mux: J2.6, U1.P10 (S0); also elsewhere on the board
S1_mux: J2.4, U1.P11 (S1); also elsewhere on the board
S2_mux: J2.10, U1.P14 (S2); also elsewhere on the board
S3_mux: J2.12, U1.P13 (S3); also elsewhere on the board
SNSR1: BlackPill1.15 (PA0), J7.3; also elsewhere on the board
SNSR2: BlackPill1.14 (PA1), J7.5; also elsewhere on the board
SNSR3: BlackPill1.13 (PA2), J7.7; also elsewhere on the board
SNSR4: BlackPill1.12 (PA3), J7.9; also elsewhere on the board
SNSR5: BlackPill1.11 (PA4), J7.13; also elsewhere on the board
SNSR6: BlackPill1.10 (PA5), J7.15; also elsewhere on the board
SNSR7: BlackPill1.9 (PA6), J7.17; also elsewhere on the board
SNSR8: BlackPill1.8 (PA7), J7.19; also elsewhere on the board
SNSR9: BlackPill1.7 (PB0), J7.11; also elsewhere on the board
STATE: BT2.1 (STATE), BlackPill1.33 (PB5)
STM_Power: BlackPill1.40 (3V3), F1.2
T1: J6.18; also elsewhere on the board
T2: J6.16; also elsewhere on the board
T3: J6.14; also elsewhere on the board
T4: J6.12; also elsewhere on the board
T5: J6.8; also elsewhere on the board
T6: J6.6; also elsewhere on the board
T7: J6.4; also elsewhere on the board
T8: J6.2; also elsewhere on the board
T9: J6.10; also elsewhere on the board
TXD: BT2.2 (TXD), BlackPill1.27 (PA10)

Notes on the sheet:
Kill switches
On the Body
Sensors
Mounting holes
Programming buttons
Fuse
Battery
Power
On the Arrays
Microbuck
Ribbons
Motor
TB6612
MCU
Motor connectors
Multiplexer
HC-05

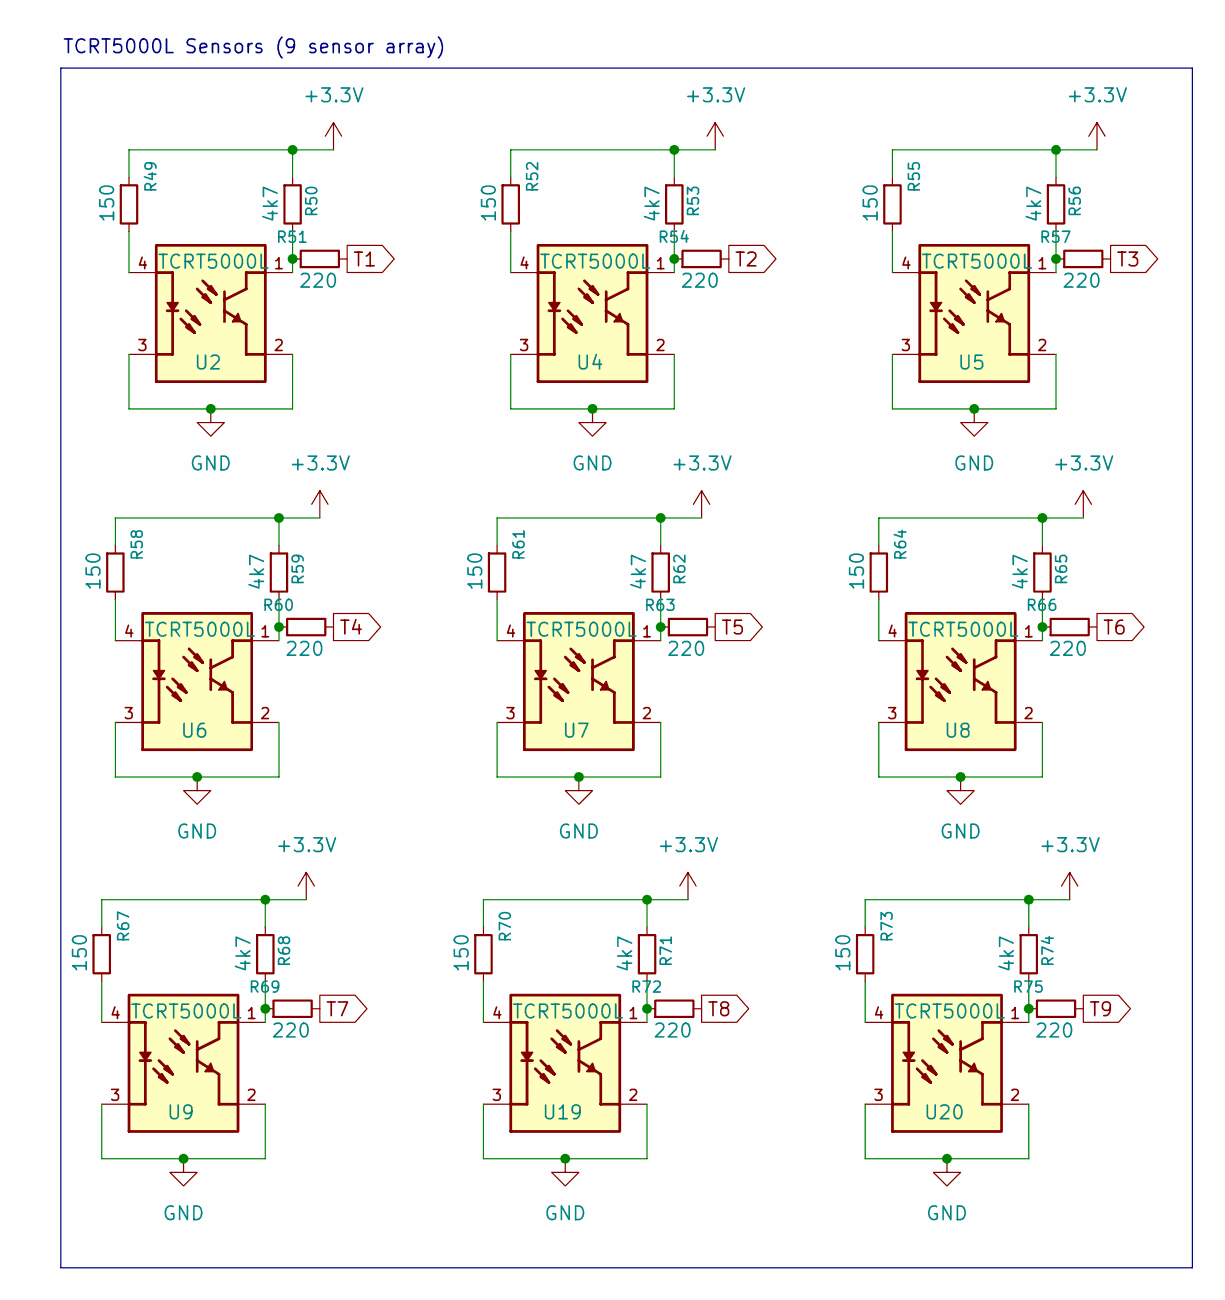
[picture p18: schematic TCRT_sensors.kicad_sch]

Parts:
R49, R52, R55, R58, R61, R64, R67, R70, R73: 150; R_0603_1608Metric_Pad0.98x0.95mm_HandSolder
R50, R53, R56, R59, R62, R65, R68, R71, R74: 4k7; R_0603_1608Metric_Pad0.98x0.95mm_HandSolder
R51, R54, R57, R60, R63, R66, R69, R72, R75: 220; R_0603_1608Metric_Pad0.98x0.95mm_HandSolder
U2, U4, U5, U6, U7, U8, U9, U19, U20: TCRT5000L; XDCR_TCRT5000L

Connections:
+3.3V: R49.1, R50.1, R52.1, R53.1, R55.1, R56.1, R58.1, R59.1, R61.1, R62.1, R64.1, R65.1, R67.1, R68.1, R70.1, R71.1, R73.1, R74.1; also elsewhere on the board
GND: U2.2, U2.3, U4.2, U4.3, U5.2, U5.3, U6.2, U6.3, U7.2, U7.3, U8.2, U8.3, U9.2, U9.3, U19.2, U19.3, U20.2, U20.3; also elsewhere on the board
unnamed: R49.2, U2.4
unnamed: R50.2, R51.1, U2.1
unnamed: R52.2, U4.4
unnamed: R53.2, R54.1, U4.1
unnamed: R55.2, U5.4
unnamed: R56.2, R57.1, U5.1
unnamed: R58.2, U6.4
unnamed: R59.2, R60.1, U6.1
unnamed: R61.2, U7.4
unnamed: R62.2, R63.1, U7.1
unnamed: R64.2, U8.4
unnamed: R65.2, R66.1, U8.1
unnamed: R67.2, U9.4
unnamed: R68.2, R69.1, U9.1
unnamed: R70.2, U19.4
unnamed: R71.2, R72.1, U19.1
unnamed: R73.2, U20.4
unnamed: R74.2, R75.1, U20.1
T1: R51.2; also elsewhere on the board
T2: R54.2; also elsewhere on the board
T3: R57.2; also elsewhere on the board
T4: R60.2; also elsewhere on the board
T5: R63.2; also elsewhere on the board
T6: R66.2; also elsewhere on the board
T7: R69.2; also elsewhere on the board
T8: R72.2; also elsewhere on the board
T9: R75.2; also elsewhere on the board

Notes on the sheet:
TCRT5000L Sensors (9 sensor array)

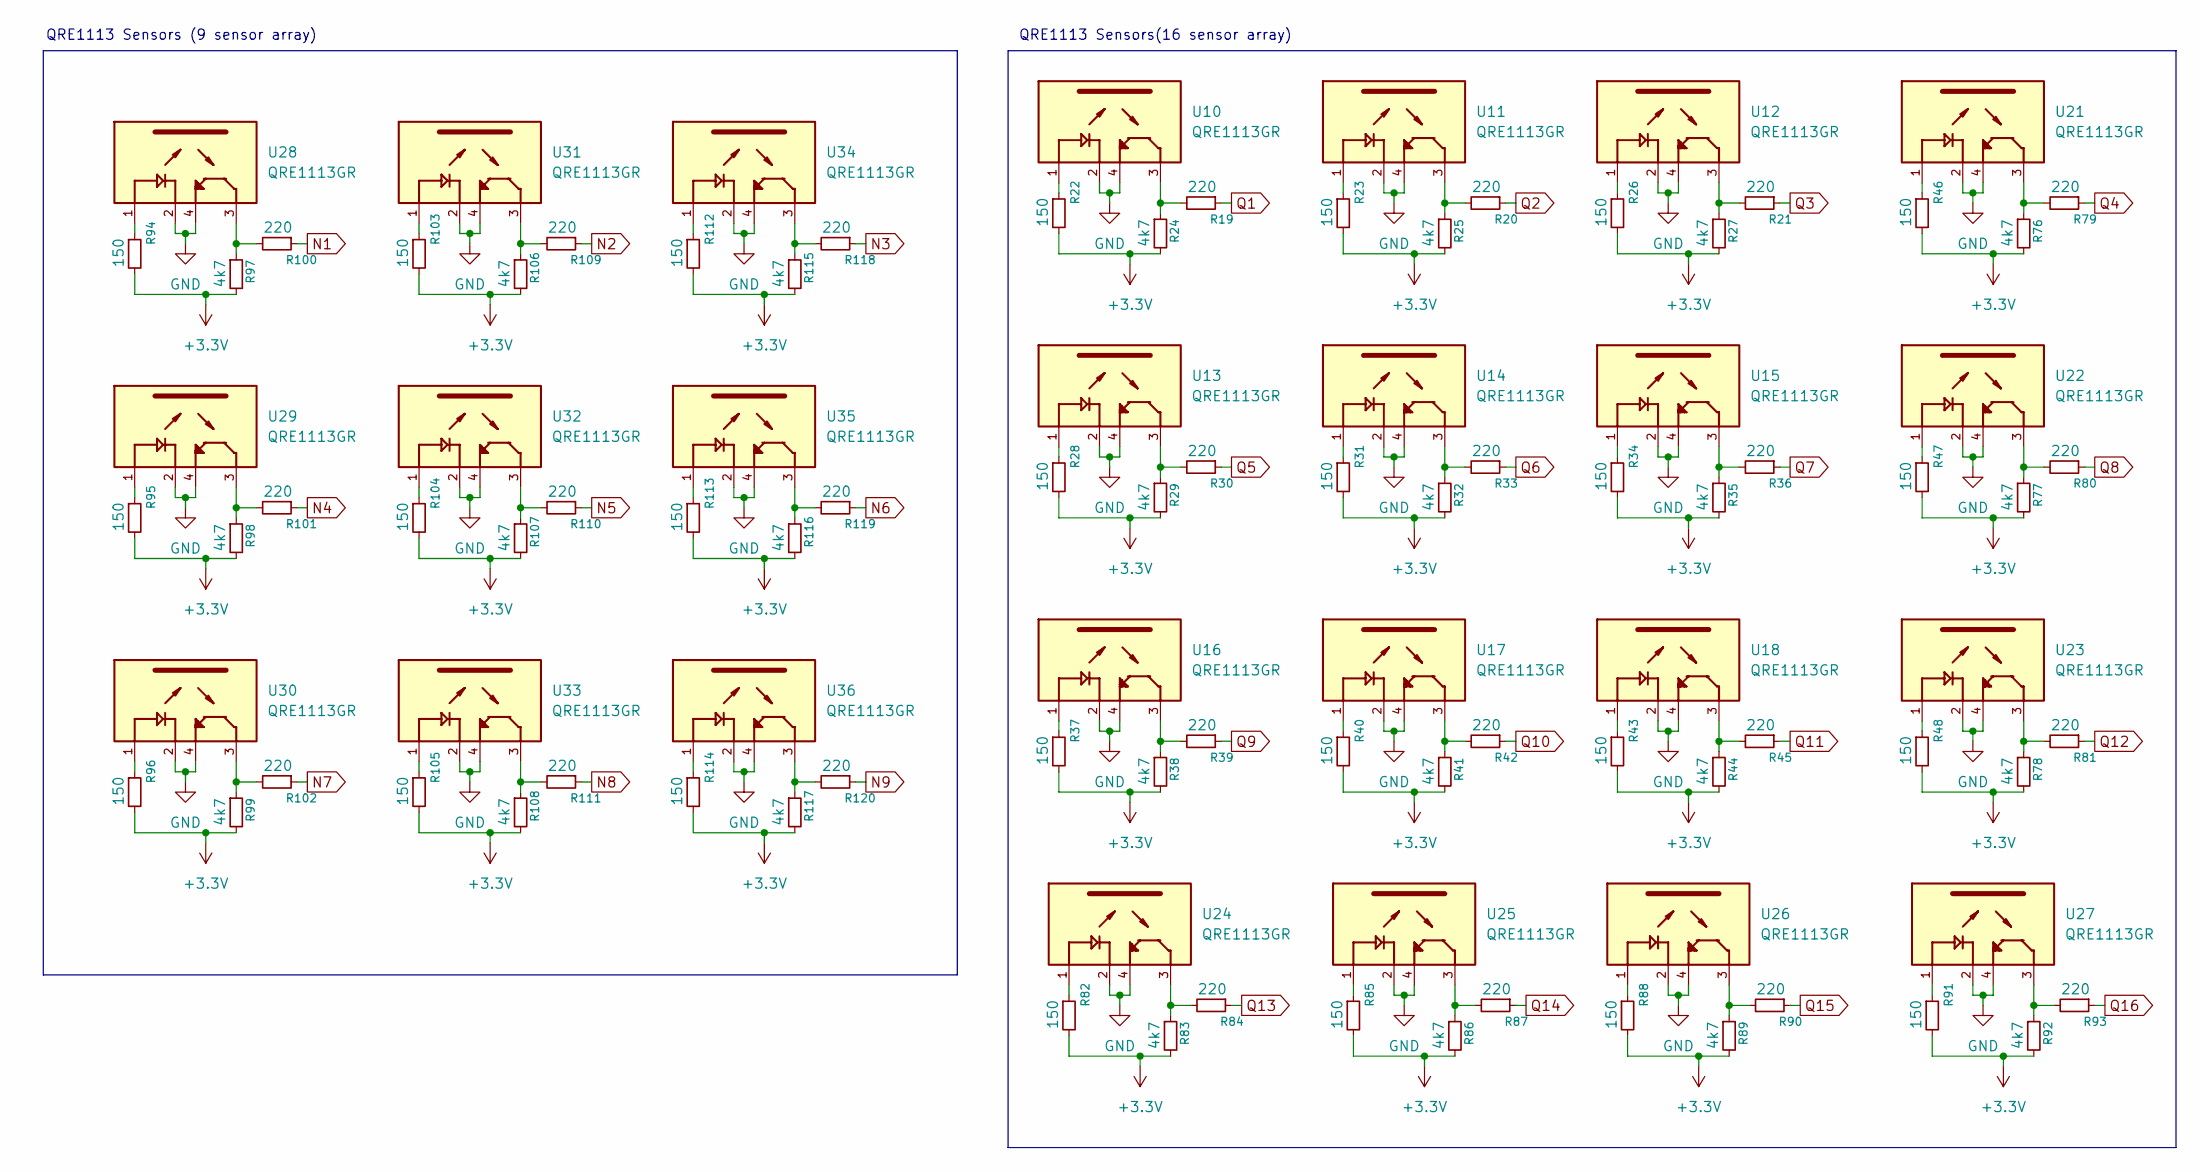
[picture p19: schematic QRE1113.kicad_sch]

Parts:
R19, R20, R21, R30, R33, R36, R39, R42, R45, R79, R80, R81, R84, R87, R90, R93, R100, R101, R102, R109, R110, R111, R118, R119, R120: 220; R_0603_1608Metric_Pad0.98x0.95mm_HandSolder
R22, R23, R26, R28, R31, R34, R37, R40, R43, R46, R47, R48, R82, R85, R88, R91, R94, R95, R96, R103, R104, R105, R112, R113, R114: 150; R_0603_1608Metric_Pad0.98x0.95mm_HandSolder
R24, R25, R27, R29, R32, R35, R38, R41, R44, R76, R77, R78, R83, R86, R89, R92, R97, R98, R99, R106, R107, R108, R115, R116, R117: 4k7; R_0603_1608Metric_Pad0.98x0.95mm_HandSolder
U10, U11, U12, U13, U14, U15, U16, U17, U18, U21, U22, U23, U24, U25, U26, U27, U28, U29, U30, U31, U32, U33, U34, U35, U36: QRE1113GR; QRE1113-SMD; PARTREV 5

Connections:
+3.3V: R22.2, R23.2, R24.2, R25.2, R26.2, R27.2, R28.2, R29.2, R31.2, R32.2, R34.2, R35.2, R37.2, R38.2, R40.2, R41.2, R43.2, R44.2, R46.2, R47.2, R48.2, R76.2, R77.2, R78.2, R82.2, R83.2, R85.2, R86.2, R88.2, R89.2, R91.2, R92.2, R94.2, R95.2, R96.2, R97.2, R98.2, R99.2, R103.2, R104.2, R105.2, R106.2, R107.2, R108.2, R112.2, R113.2, R114.2, R115.2, R116.2, R117.2; also elsewhere on the board
GND: U10.2, U10.4, U11.2, U11.4, U12.2, U12.4, U13.2, U13.4, U14.2, U14.4, U15.2, U15.4, U16.2, U16.4, U17.2, U17.4, U18.2, U18.4, U21.2, U21.4, U22.2, U22.4, U23.2, U23.4, U24.2, U24.4, U25.2, U25.4, U26.2, U26.4, U27.2, U27.4, U28.2, U28.4, U29.2, U29.4, U30.2, U30.4, U31.2, U31.4, U32.2, U32.4, U33.2, U33.4, U34.2, U34.4, U35.2, U35.4, U36.2, U36.4; also elsewhere on the board
N1: R100.1; also elsewhere on the board
N2: R109.1; also elsewhere on the board
N3: R118.1; also elsewhere on the board
N4: R101.1; also elsewhere on the board
N5: R110.1; also elsewhere on the board
N6: R119.1; also elsewhere on the board
N7: R102.1; also elsewhere on the board
N8: R111.1; also elsewhere on the board
N9: R120.1; also elsewhere on the board
unnamed: R19.2, R24.1, U10.3
unnamed: R20.2, R25.1, U11.3
unnamed: R21.2, R27.1, U12.3
unnamed: R22.1, U10.1
unnamed: R23.1, U11.1
unnamed: R26.1, U12.1
unnamed: R28.1, U13.1
unnamed: R29.1, R30.2, U13.3
unnamed: R31.1, U14.1
unnamed: R32.1, R33.2, U14.3
unnamed: R34.1, U15.1
unnamed: R35.1, R36.2, U15.3
unnamed: R37.1, U16.1
unnamed: R38.1, R39.2, U16.3
unnamed: R40.1, U17.1
unnamed: R41.1, R42.2, U17.3
unnamed: R43.1, U18.1
unnamed: R44.1, R45.2, U18.3
unnamed: R46.1, U21.1
unnamed: R47.1, U22.1
unnamed: R48.1, U23.1
unnamed: R76.1, R79.2, U21.3
unnamed: R77.1, R80.2, U22.3
unnamed: R78.1, R81.2, U23.3
unnamed: R82.1, U24.1
unnamed: R83.1, R84.2, U24.3
unnamed: R85.1, U25.1
unnamed: R86.1, R87.2, U25.3
unnamed: R88.1, U26.1
unnamed: R89.1, R90.2, U26.3
unnamed: R91.1, U27.1
unnamed: R92.1, R93.2, U27.3
unnamed: R94.1, U28.1
unnamed: R95.1, U29.1
unnamed: R96.1, U30.1
unnamed: R97.1, R100.2, U28.3
unnamed: R98.1, R101.2, U29.3
unnamed: R99.1, R102.2, U30.3
unnamed: R103.1, U31.1
unnamed: R104.1, U32.1
unnamed: R105.1, U33.1
unnamed: R106.1, R109.2, U31.3
unnamed: R107.1, R110.2, U32.3
unnamed: R108.1, R111.2, U33.3
unnamed: R112.1, U34.1
unnamed: R113.1, U35.1
unnamed: R114.1, U36.1
unnamed: R115.1, R118.2, U34.3
unnamed: R116.1, R119.2, U35.3
unnamed: R117.1, R120.2, U36.3
Q1: R19.1; also elsewhere on the board
Q2: R20.1; also elsewhere on the board
Q3: R21.1; also elsewhere on the board
Q4: R79.1; also elsewhere on the board
Q5: R30.1; also elsewhere on the board
Q6: R33.1; also elsewhere on the board
Q7: R36.1; also elsewhere on the board
Q8: R80.1; also elsewhere on the board
Q9: R39.1; also elsewhere on the board
Q10: R42.1; also elsewhere on the board
Q11: R45.1; also elsewhere on the board
Q12: R81.1; also elsewhere on the board
Q13: R84.1; also elsewhere on the board
Q14: R87.1; also elsewhere on the board
Q15: R90.1; also elsewhere on the board
Q16: R93.1; also elsewhere on the board

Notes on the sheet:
QRE1113 Sensors (9 sensor array)
QRE1113 Sensors(16 sensor array)

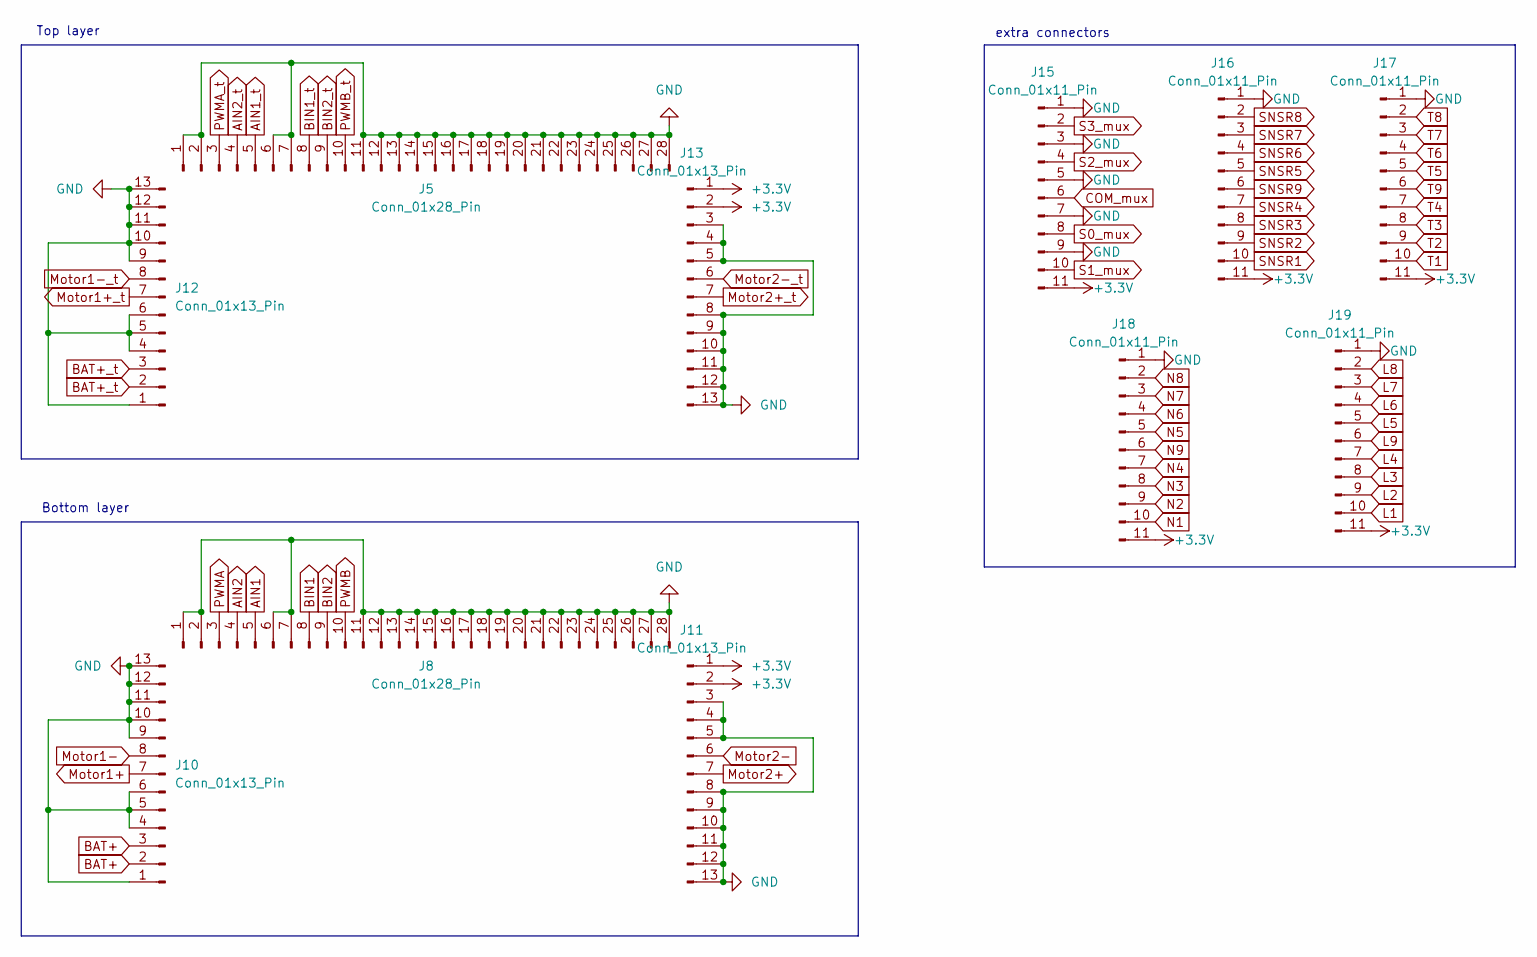
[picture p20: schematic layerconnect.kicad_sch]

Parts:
J5, J8: Conn_01x28_Pin; PinHeader_1x28_P2.54mm_Vertical
J10, J11, J12, J13: Conn_01x13_Pin; PinHeader_1x13_P2.54mm_Vertical
J15, J16, J17, J18, J19: Conn_01x11_Pin; PinHeader_1x11_P2.54mm_Vertical

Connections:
+3.3V: J11.1, J11.2, J13.1, J13.2, J15.11, J16.11, J17.11, J18.11, J19.11; also elsewhere on the board
AIN1: J8.5; also elsewhere on the board
AIN1_t: J5.5; also elsewhere on the board
AIN2: J8.4; also elsewhere on the board
AIN2_t: J5.4; also elsewhere on the board
BAT+: J10.2, J10.3; also elsewhere on the board
BAT+_t: J12.2, J12.3; also elsewhere on the board
BIN1: J8.8; also elsewhere on the board
BIN1_t: J5.8; also elsewhere on the board
BIN2: J8.9; also elsewhere on the board
BIN2_t: J5.9; also elsewhere on the board
COM_mux: J15.6; also elsewhere on the board
GND: J5.1, J5.2, J5.6, J5.7, J5.11, J5.12, J5.13, J5.14, J5.15, J5.16, J5.17, J5.18, J5.19, J5.20, J5.21, J5.22, J5.23, J5.24, J5.25, J5.26, J5.27, J5.28, J8.1, J8.2, J8.6, J8.7, J8.11, J8.12, J8.13, J8.14, J8.15, J8.16, J8.17, J8.18, J8.19, J8.20, J8.21, J8.22, J8.23, J8.24, J8.25, J8.26, J8.27, J8.28, J10.1, J10.4, J10.5, J10.6, J10.9, J10.10, J10.11, J10.12, J10.13, J11.3, J11.4, J11.5, J11.8, J11.9, J11.10, J11.11, J11.12, J11.13, J12.1, J12.4, J12.5, J12.6, J12.9, J12.10, J12.11, J12.12, J12.13, J13.3, J13.4, J13.5, J13.8, J13.9, J13.10, J13.11, J13.12, J13.13, J15.1, J15.3, J15.5, J15.7, J15.9, J16.1, J17.1, J18.1, J19.1; also elsewhere on the board
L1: J19.10; also elsewhere on the board
L2: J19.9; also elsewhere on the board
L3: J19.8; also elsewhere on the board
L4: J19.7; also elsewhere on the board
L5: J19.5; also elsewhere on the board
L6: J19.4; also elsewhere on the board
L7: J19.3; also elsewhere on the board
L8: J19.2; also elsewhere on the board
L9: J19.6; also elsewhere on the board
Motor1+: J10.7; also elsewhere on the board
Motor1+_t: J12.7; also elsewhere on the board
Motor1-: J10.8; also elsewhere on the board
Motor1-_t: J12.8; also elsewhere on the board
Motor2+: J11.7; also elsewhere on the board
Motor2+_t: J13.7; also elsewhere on the board
Motor2-: J11.6; also elsewhere on the board
Motor2-_t: J13.6; also elsewhere on the board
N1: J18.10; also elsewhere on the board
N2: J18.9; also elsewhere on the board
N3: J18.8; also elsewhere on the board
N4: J18.7; also elsewhere on the board
N5: J18.5; also elsewhere on the board
N6: J18.4; also elsewhere on the board
N7: J18.3; also elsewhere on the board
N8: J18.2; also elsewhere on the board
N9: J18.6; also elsewhere on the board
PWMA: J8.3; also elsewhere on the board
PWMA_t: J5.3; also elsewhere on the board
PWMB: J8.10; also elsewhere on the board
PWMB_t: J5.10; also elsewhere on the board
S0_mux: J15.8; also elsewhere on the board
S1_mux: J15.10; also elsewhere on the board
S2_mux: J15.4; also elsewhere on the board
S3_mux: J15.2; also elsewhere on the board
SNSR1: J16.10; also elsewhere on the board
SNSR2: J16.9; also elsewhere on the board
SNSR3: J16.8; also elsewhere on the board
SNSR4: J16.7; also elsewhere on the board
SNSR5: J16.5; also elsewhere on the board
SNSR6: J16.4; also elsewhere on the board
SNSR7: J16.3; also elsewhere on the board
SNSR8: J16.2; also elsewhere on the board
SNSR9: J16.6; also elsewhere on the board
T1: J17.10; also elsewhere on the board
T2: J17.9; also elsewhere on the board
T3: J17.8; also elsewhere on the board
T4: J17.7; also elsewhere on the board
T5: J17.5; also elsewhere on the board
T6: J17.4; also elsewhere on the board
T7: J17.3; also elsewhere on the board
T8: J17.2; also elsewhere on the board
T9: J17.6; also elsewhere on the board

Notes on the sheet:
Top layer
extra connectors
Bottom layer

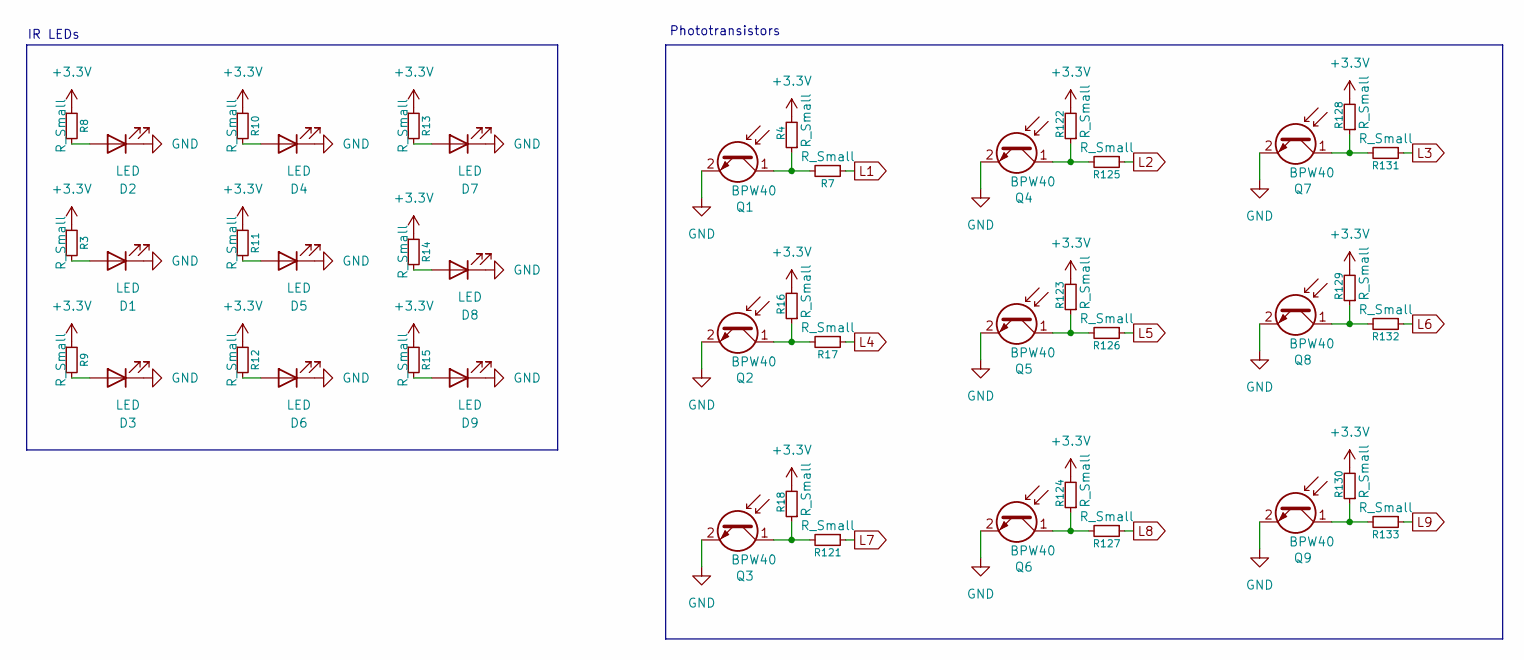
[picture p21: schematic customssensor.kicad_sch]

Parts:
D1, D2, D3, D4, D5, D6, D7, D8, D9: LED; LED_D5.0mm_Clear
Q1, Q2, Q3, Q4, Q5, Q6, Q7, Q8, Q9: BPW40; LED_D5.0mm_Clear
R3, R4, R7, R8, R9, R10, R11, R12, R13, R14, R15, R16, R17, R18, R121, R122, R123, R124, R125, R126, R127, R128, R129, R130, R131, R132, R133: R_Small; R_0603_1608Metric_Pad0.98x0.95mm_HandSolder

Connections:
+3.3V: R3.1, R4.2, R8.1, R9.1, R10.1, R11.1, R12.1, R13.1, R14.1, R15.1, R16.2, R18.2, R122.2, R123.2, R124.2, R128.2, R129.2, R130.2; also elsewhere on the board
GND: D1.1 (K), D2.1 (K), D3.1 (K), D4.1 (K), D5.1 (K), D6.1 (K), D7.1 (K), D8.1 (K), D9.1 (K), Q1.2 (E), Q2.2 (E), Q3.2 (E), Q4.2 (E), Q5.2 (E), Q6.2 (E), Q7.2 (E), Q8.2 (E), Q9.2 (E); also elsewhere on the board
L1: R7.1; also elsewhere on the board
L2: R125.1; also elsewhere on the board
L3: R131.1; also elsewhere on the board
L4: R17.1; also elsewhere on the board
L5: R126.1; also elsewhere on the board
L6: R132.1; also elsewhere on the board
L7: R121.1; also elsewhere on the board
L8: R127.1; also elsewhere on the board
L9: R133.1; also elsewhere on the board
unnamed: D1.2 (A), R3.2
unnamed: D2.2 (A), R8.2
unnamed: D3.2 (A), R9.2
unnamed: D4.2 (A), R10.2
unnamed: D5.2 (A), R11.2
unnamed: D6.2 (A), R12.2
unnamed: D7.2 (A), R13.2
unnamed: D8.2 (A), R14.2
unnamed: D9.2 (A), R15.2
unnamed: Q1.1 (C), R4.1, R7.2
unnamed: Q2.1 (C), R16.1, R17.2
unnamed: Q3.1 (C), R18.1, R121.2
unnamed: Q4.1 (C), R122.1, R125.2
unnamed: Q5.1 (C), R123.1, R126.2
unnamed: Q6.1 (C), R124.1, R127.2
unnamed: Q7.1 (C), R128.1, R131.2
unnamed: Q8.1 (C), R129.1, R132.2
unnamed: Q9.1 (C), R130.1, R133.2

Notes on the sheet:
Phototransistors
IR LEDs

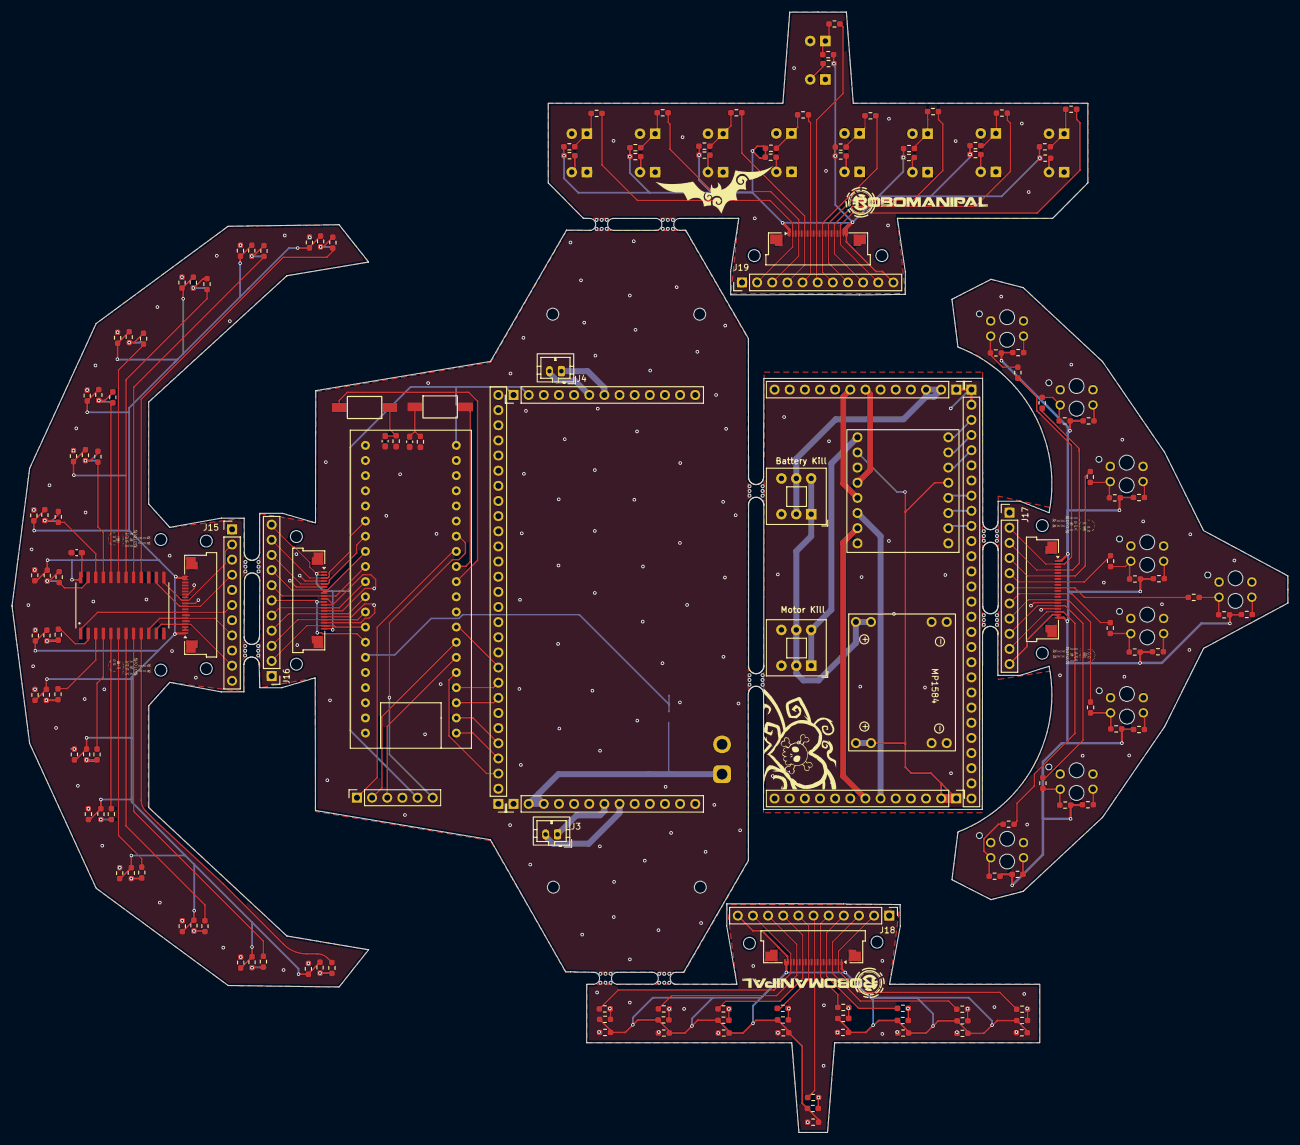
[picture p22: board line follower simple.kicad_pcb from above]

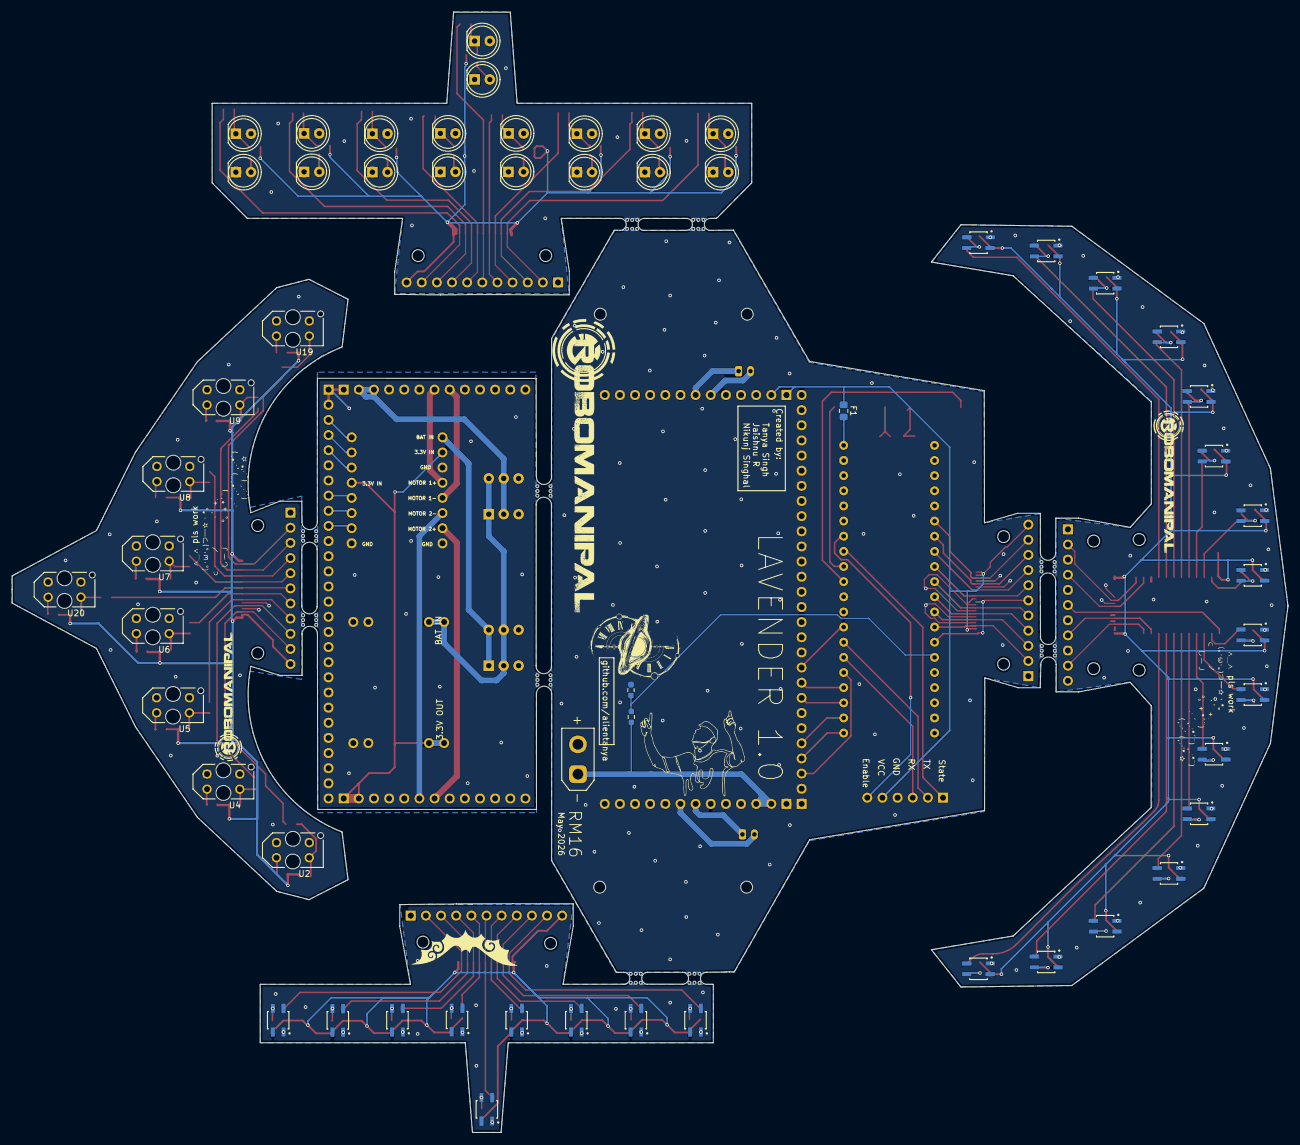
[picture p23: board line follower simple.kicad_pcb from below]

Board: 2 copper layers, 214.0 x 187.9 mm, 235 parts (56 on the bottom side), 179 nets.

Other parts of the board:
mouse-bite-2.54mm-slot, mouse-bite-2.54mm-slot#2, mouse-bite-2.54mm-slot#3, mouse-bite-2.54mm-slot#4, mouse-bite-2.54mm-slot#5, mouse-bite-2.54mm-slot#6: VAL**; mouse-bite-2.54mm-slot

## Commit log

2026-04-03 Updated schematic
    [flf.kicad_sch]
2026-04-03 Added switches
    [BNO055--3DModel-STEP-56544.STEP, BNO055.step, QRE1113GR--3DModel-STEP-418109.STEP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]
2026-04-04 Completed schematic layout
    [2472.STEP, 2472.step, BNO055--3DModel-STEP-56544.STEP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]
2026-04-05 Fixed ERC error
    [2472.step, line follower simple.kicad_sch, untitled.kicad_sch]
2026-04-07 arrange pcb components
    [line follower simple.kicad_pcb, line follower simple.kicad_sch, untitled.kicad_sch]
2026-04-11 started routing
    [layerconnect.kicad_sch, line follower simple.kicad_pcb, line follower simple.kicad_sch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]
2026-04-12 Finished 16 sensor array
    [line follower simple.kicad_pcb, line follower simple.kicad_sch]
2026-04-14 Start third sensor array
    [TCRT_sensors.kicad_sch, line follower simple.kicad_pcb, line follower simple.kicad_sch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]
2026-04-15 Start custom sensor array
    [TCRT_sensors.kicad_sch, customssensor.kicad_sch, line follower simple.kicad_pcb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]
2026-04-16 Finished PCB
    [customssensor.kicad_sch, line follower simple.kicad_sch]
2026-04-23 Curved array for tcrt500
    [STMf411.kicad_sch, TCRT_sensors.kicad_sch, customssensor.kicad_sch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]
2026-04-30 Add mousebites
    [line follower simple.kicad_sch]
2026-04-30 Add JST for motor
    [line follower simple.kicad_sch]
2026-04-30 Add silkscreen
2026-04-30 fix placement
    [line follower simple-B_Cu.gbr, line follower simple-B_Mask.gbr, line follower simple-B_Silkscreen.gbr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]
2026-04-30 Add name
    [line follower simple-B_Cu.gbr, line follower simple-B_Mask.gbr, line follower simple-B_Silkscreen.gbr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]
2026-05-19 Minor fixes
    [line follower simple-B_Cu.gbr, line follower simple-B_Mask.gbr, line follower simple-B_Silkscreen.gbr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]
2026-05-19 Add polyfuse
    [QRE1113.kicad_sch, layerconnect.kicad_sch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]
2026-05-19 Silkscreen fixes
    [line follower simple.kicad_pcb]
2026-05-20 Fix overlapping silkscreen
    [TB6612FNG--3DModel-STEP-510211.STEP, TB6612FNG.step, TB6612FNG_Lower Pins.STEP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]
2026-05-28 fix footprint
    [Assem4.STEP, FPC-05FB-20PH20.SLDPRT, G73 button.SLDPRT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]
2026-06-01 fix gitignore
    [line follower simple.kicad_pcb]
2026-06-01 gap fixes
    [line follower simple-B_Courtyard.gbr, line follower simple-B_Cu.gbr, line follower simple-B_Mask.gbr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]
2026-06-01 more gap fixes
    [line follower simple.kicad_pcb]
2026-08-02 Expand documentation
    [.step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]
